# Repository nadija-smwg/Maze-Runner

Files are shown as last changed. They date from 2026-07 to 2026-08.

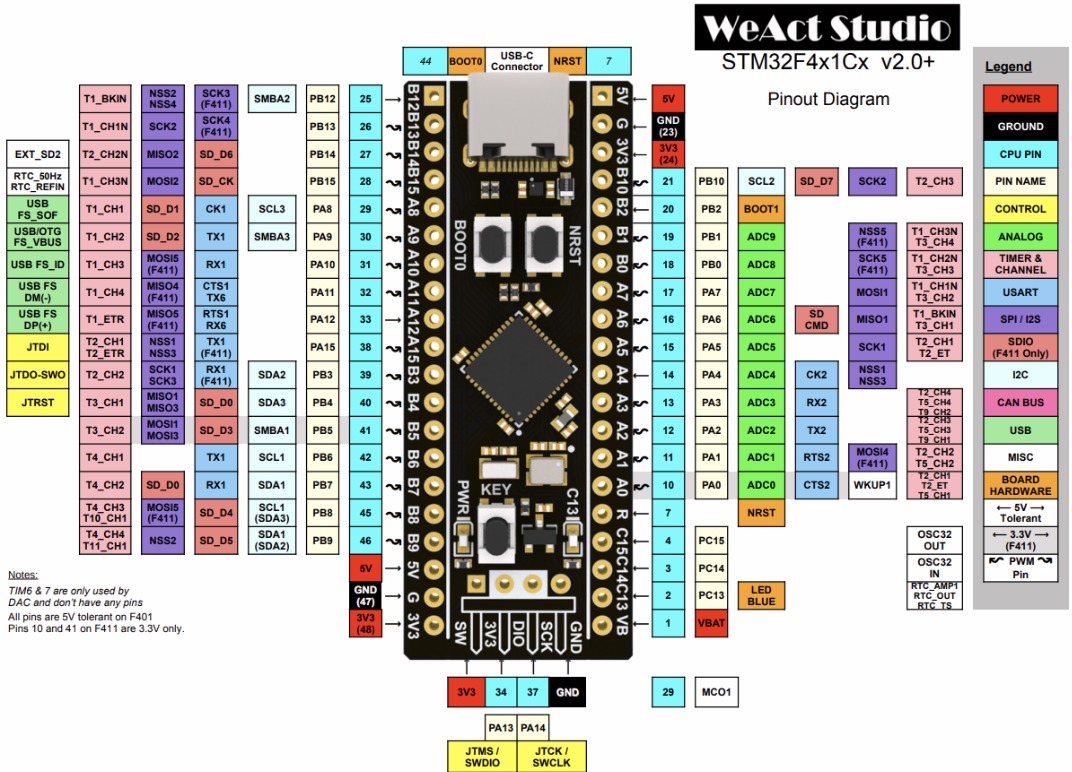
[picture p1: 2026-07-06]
Testing Codes/WhatsApp Image 2026-07-06 at 23.36.06.jpeg

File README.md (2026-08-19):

<p align="center">
  <h1 align="center">🐭 Maze Runner — Autonomous Micromouse</h1>
  <p align="center">
    <strong>A championship-grade autonomous maze-solving robot built for MicroMaze 3 (IIT IEEE RAS)</strong>
  </p>
  <p align="center">
    
    
    
    
    
  </p>
</p>

---

## 📖 Overview

**Maze Runner** is an autonomous micromouse robot designed to navigate and solve a standard IEEE 16×16 competition maze. The robot explores an unknown maze, maps its walls using onboard sensors, computes the optimal path using advanced graph algorithms, and then executes a blazing-fast speed run — all without any human intervention.

Built for the **MicroMaze 3** competition organized by the Informatics Institute of Technology (IIT) IEEE Robotics & Automation Society, with a **final competition date of August 22, 2026**.

### 🏆 Competition Details

| Detail | Info |
|---|---|
| **Event** | MicroMaze 3 — Inter-University Micromouse Competition |
| **Organizer** | IIT IEEE Student Branch (IEEE RAS Student Chapter) |
| **Maze** | 16×16 grid, 18cm × 18cm cells, 5cm walls, 1.2cm thick |
| **Max Robot Size** | 14.5cm × 14.5cm (no height limit) |
| **Trial Time** | 8 minutes per round, up to 10 runs in finals |
| **Prize Pool** | 1st: 100,000 LKR · 2nd: 70,000 LKR · 3rd: 40,000 LKR |

---

## 🏗️ System Architecture

```
┌──────────────────────────────────────────────────────────────┐
│                    MAZE RUNNER — SOFTWARE STACK               │
├──────────────────────────────────────────────────────────────┤
│                                                              │
│  ┌─────────────────────────────────────────────────────────┐ │
│  │  Tier 1: SEARCH RUN                                     │ │
│  │  ┌─────────────────────────────────────────────┐        │ │
│  │  │  🌊 Modified Flood Fill (BFS)                │        │ │
│  │  │  • Multi-source BFS from goal cells         │        │ │
│  │  │  • Straight-preference tie-breaking         │        │ │
│  │  │  • Recomputes per cell on new wall data     │        │ │
│  │  └─────────────────────────────────────────────┘        │ │
│  └─────────────────────────────────────────────────────────┘ │
│                          ▼                                   │
│  ┌─────────────────────────────────────────────────────────┐ │
│  │  Tier 2: FAST-RUN PATH PLANNING                         │ │
│  │  ┌─────────────────────────────────────────────┐        │ │
│  │  │  🔬 Weighted Dijkstra (3D State Space)       │        │ │
│  │  │  • State = (x, y, heading) → 1024 states    │        │ │
│  │  │  • Turn penalties: 90° = +12, 180° = +30    │        │ │
│  │  │  • Binary min-heap priority queue            │        │ │
│  │  └─────────────────────────────────────────────┘        │ │
│  └─────────────────────────────────────────────────────────┘ │
│                          ▼                                   │
│  ┌─────────────────────────────────────────────────────────┐ │
│  │  Tier 3: MOTION OPTIMIZATION                             │ │
│  │  ┌─────────────────────────────────────────────┐        │ │
│  │  │  🎯 Path Smoother (Look-Ahead)               │        │ │
│  │  │  • Straight-run merging                     │        │ │
│  │  │  • Rolling turn classification              │        │ │
│  │  │  • Diagonal detection (optional)            │        │ │
│  │  └─────────────────────────────────────────────┘        │ │
│  └─────────────────────────────────────────────────────────┘ │
│                          ▼                                   │
│  ┌─────────────────────────────────────────────────────────┐ │
│  │  Tier 4: VELOCITY PROFILE GENERATION                     │ │
│  │  ┌─────────────────────────────────────────────┐        │ │
│  │  │  🏎️ S-Curve & Rolling Turn Profiles          │        │ │
│  │  │  • Jerk-limited S-curve acceleration        │        │ │
│  │  │  • Circular arc turn profiles               │        │ │
│  │  │  • Differential wheel speed computation     │        │ │
│  │  └─────────────────────────────────────────────┘        │ │
│  └─────────────────────────────────────────────────────────┘ │
│                          ▼                                   │
│  ┌─────────────────────────────────────────────────────────┐ │
│  │  LOCOMOTION LAYER                                        │ │
│  │  PID Control → TB6612FNG Motor Driver → N20 Motors      │ │
│  └─────────────────────────────────────────────────────────┘ │
└──────────────────────────────────────────────────────────────┘
```

---

## ⚙️ Hardware Platform

| Component | Part | Specification |
|---|---|---|
| **MCU** | STM32F401CCU6 "Black Pill" | 84 MHz ARM Cortex-M4F, 256KB Flash, 64KB RAM |
| **Motor Driver** | TB6612FNG | Dual H-bridge, 1.2A continuous per channel |
| **Motors** | N20 micro gearmotors | 300 RPM with magnetic quadrature encoders |
| **Wall Sensors** | VL53L0X (ToF) | 5× I2C Time-of-Flight distance sensors |
| **IMU** | MPU6050 | 6-axis accelerometer + gyroscope for yaw correction |
| **Power** | 2× 3.7V LiPo | 7.4V total, buck-regulated to 3.3V/5V rails |
| **IDE** | Arduino IDE + GCC | STM32duino core for HAL, GCC for algorithm testing |

### 📌 Pin Assignments

| Function | Pin(s) | Peripheral |
|---|---|---|
| Motor A PWM | `PA8` | TIM1 CH1 |
| Motor A Direction | `PB12`, `PB13` | GPIO |
| Motor B PWM | `PA9` | TIM1 CH2 |
| Motor B Direction | `PB15`, `PA10` | GPIO |
| Motor Driver Standby | `PB14` | GPIO |
| Left Encoder (A/B) | `PA0`, `PA1` | TIM2 CH1/CH2 (Encoder Mode 3) |
| Right Encoder (A/B) | `PA6`, `PA7` | TIM3 CH1/CH2 (Encoder Mode 3) |
| VL53L0X XSHUT | `PA4`, `PA15`, `PB3`, `PB1`, `PC14` | GPIO (Front, L-45, R-45, L-90, R-90) |
| I2C (IMU + ToF) | `PB8` (SCL), `PB9` (SDA) | I2C1 |
| Status LED (Ext) | `PA5` | GPIO (Active HIGH) |
| Debug LED (Onbd) | `PC13` | GPIO (Active LOW) |
| Start Button | `PB5` | GPIO (INPUT_PULLUP) |
| Mode Button | `PB4` | GPIO (INPUT_PULLUP) |
| Battery Sense | `PB0` | ADC Input |

---

## 📂 Project Structure

```
Maze-Runner/
│
├── src/                            # Core algorithm suite (pure C, desktop-testable)
│   ├── config.h                    # All tunable parameters (speeds, costs, geometry)
│   ├── maze.h                      # Maze data structures, wall operations, direction system
│   ├── flood_fill.h / .c           # Tier 1: Modified Flood Fill (BFS) for search run
│   ├── dijkstra_weighted.h / .c    # Tier 2: Weighted Dijkstra with turn penalties
│   ├── path_smoother.h / .c        # Tier 3: Waypoint → motion command converter
│   ├── motion_profile.h / .c       # Tier 4: S-curve & arc turn velocity profiles
│   ├── solver.h / .c               # Top-level orchestrator (ties all tiers together)
│   ├── main.c                      # Desktop test harness & algorithm demo
│   ├── maze_test.exe               # Compiled test binary (Windows)
│   └── worksheet.md                # Algorithm deep-dive & developer manual
│
├── Testing Codes/                  # Hardware component validation sketches (Arduino)
│   ├── MPU6050/MPU6050.ino         # IMU calibration, complementary filter, yaw tracking
│   ├── VL53L0X/VL53L0X.ino        # ToF sensor register-level distance reading
│   ├── Motors/Motors.ino           # Basic motor forward/reverse/stop test
│   ├── Motors (Advanced)/          # Advanced motor control test
│   └── Motors_With_Encoders/       # Quadrature encoder (register-level TIM2/TIM3)
│       └── Motors_With_Encoders.ino
│
├── bin/                            # Learning curriculum (5-phase embedded track)
│   ├── 00-README.md                # Curriculum overview & phase map
│   ├── 01-phase1-baremetal.md      # STM32 toolchain, clocks, GPIO, timers
│   ├── 02-phase2-sensors-actuators.md  # PWM, encoders, ADC, I2C/SPI
│   ├── 03-phase3-kinematics-control.md # Dead reckoning, PID, sensor fusion
│   ├── 04-phase4-maze-solving.md   # Maze modeling, flood fill, path translation
│   └── 05-phase5-competition-optimization.md  # State machine, speed tuning
│
├── plan/                           # Build guide & competition documentation
│   ├── 00_INDEX.md                 # Master document index & build order
│   ├── 01_HARDWARE_OVERVIEW.md     # Component roles & specifications
│   ├── 02_ADDITIONAL_COMPONENTS.md # Bill of materials & procurement list
│   ├── 03_PIN_DIAGRAM_WIRING.md    # Full wiring tables & connection diagrams
│   ├── 04_PCB_PLACEMENT_THERMAL.md # Physical layout & thermal management
│   ├── 05_TESTING_STAGES.md        # Step-by-step hardware testing procedures
│   ├── 06_MAIN_LOGIC_CODE.md       # Maze-solving logic & final firmware code
│   ├── 07_TUNING_CALIBRATION.md    # PID tuning & sensor calibration guide
│   ├── 08_TROUBLESHOOTING.md       # Common problems & fixes
│   ├── 09_SPEED_RUN.md             # Speed run strategy & velocity profiling
│   ├── 10_COMPETITION_PREP.md      # Competition rules & checklists
│   ├── 11_DATA_LOGGING.md          # Telemetry, Bluetooth, Python visualization
│   └── MicroMaze_3_Delegate_Booklet.md  # Official competition rulebook
│
└── README.md                       # ← You are here
```

---

## 🧠 Algorithm Suite

### Tier 1 — Modified Flood Fill (Search Run)
The robot explores the unknown maze using a **multi-source BFS** flood fill. At each cell, it reads wall data from sensors, updates the internal maze map, and recomputes shortest distances to the goal. A critical **straight-preference tie-breaker** avoids unnecessary turns during exploration.

- **Complexity:** O(256) per recompute — executes in <10µs on Cortex-M4 @ 100MHz
- **Queue:** Fixed-size ring buffer (zero heap allocation)

### Tier 2 — Weighted Dijkstra (Fast-Run Path)
After exploration, the robot computes a **time-optimal** path using Dijkstra's algorithm on a 3D state space `(x, y, heading)` = 1,024 states. Turn penalties make it prefer straighter paths even if slightly longer in cell count.

- **Cost Model:** `STRAIGHT = 10` | `+TURN_90 = 12` | `+TURN_180 = 30`
- **Priority Queue:** Custom binary min-heap (executes in <2ms on STM32)

### Tier 3 — Path Smoother (Motion Commands)
Raw waypoints are converted into optimized motor commands:
- Consecutive same-heading moves → single `STRAIGHT(n)` command
- Heading changes with entry/exit momentum → `SMOOTH_ROLLING_TURN` (no stop)
- Dead-end turns → `IN_PLACE_TURN` (stop, rotate, resume)

### Tier 4 — S-Curve Motion Profile
Velocity targets are computed using **jerk-limited S-curve profiles** to prevent wheel slip:
- Sinusoidal acceleration ramps: `v = v_start + (v_peak - v_start) × sin²(progress)`
- Rolling arc turn profiles with differential wheel speed computation
- **Look-ahead planning**: pre-computes deceleration for upcoming turns

---

## 🔧 Memory Footprint

The entire algorithm suite uses **zero dynamic memory allocation** — all structures are fixed-size and statically allocated, critical for reliability on embedded systems.

| Structure | Size | Notes |
|---|---|---|
| `MazeMap` (16×16 cells) | ~1,280 bytes | 5 bytes per cell × 256 cells |
| `DijkstraResult` | ~1,030 bytes | 256 waypoints + metadata |
| `SmoothedPath` | ~640 bytes | 128 motion commands |
| `Solver` (complete state) | ~3,200 bytes | Includes maze + paths + commands |
| **Total Algorithm RAM** | **< 4 KB** | Out of 128 KB available |

---

## 📊 Current Progress

### Development Phases

| Phase | Description | Status |
|:---:|---|:---:|
| 1 | **STM32 Bare-Metal Fundamentals** — Toolchain, clocks, GPIO, timers | ✅ Complete |
| 2 | **Sensor & Actuator Interfacing** — Motors, encoders, VL53L0X, MPU6050 | ✅ Complete |
| 3 | **Kinematics & Control** — Dead reckoning, PID, sensor fusion | 🔧 In Progress |
| 4 | **Maze-Solving Algorithms** — Flood fill, Dijkstra, path smoother | ✅ Complete |
| 5 | **Competition Optimization** — State machine, speed tuning, robustness | 🔲 Pending |

### Software Modules

| Module | File(s) | Status | Notes |
|---|---|:---:|---|
| Maze Data Structures | `maze.h`, `config.h` | ✅ Done | Zero-alloc, embedded-safe |
| Modified Flood Fill | `flood_fill.c/.h` | ✅ Done | BFS + straight-preference tie-break |
| Weighted Dijkstra | `dijkstra_weighted.c/.h` | ✅ Done | 3D state space, binary min-heap |
| Path Smoother | `path_smoother.c/.h` | ✅ Done | Straight merging, rolling turn classification |
| Motion Profile | `motion_profile.c/.h` | ✅ Done | S-curve, arc turns, wheel speed diff |
| Solver Orchestrator | `solver.c/.h` | ✅ Done | Ties all tiers together |
| Desktop Test Harness | `main.c` | ✅ Done | Full algorithm demo on simulated maze |
| PID Controller | — | 🔧 WIP | Needed for motor control integration |
| STM32 Main Firmware | — | 🔲 Pending | Final firmware integrating all modules |

### Hardware Testing

| Component | Test Sketch | Status | Notes |
|---|---|:---:|---|
| Motor Basic Control | `Motors.ino` | ✅ Tested | Forward/reverse/stop via TB6612FNG |
| Motor Advanced | `Motors (Advanced).ino` | ✅ Tested | Extended motor control |
| Quadrature Encoders | `Motors_With_Encoders.ino` | ✅ Tested | Register-level TIM2/TIM3, 0.178 mm/count |
| VL53L0X ToF Sensor | `VL53L0X.ino` | ✅ Tested | Register-level I2C, single-shot ranging |
| MPU6050 IMU | `MPU6050.ino` | ✅ Tested | Calibration, complementary filter, yaw |

---

## 🚀 Quick Start

### Build & Run the Algorithm Test Suite (Desktop)

```bash
# Compile the desktop test harness
cd src/
gcc -o maze_test main.c flood_fill.c dijkstra_weighted.c path_smoother.c solver.c motion_profile.c -lm

# Run the full algorithm demo
./maze_test
```

This runs a complete simulation on a hardcoded 16×16 competition-style maze:
1. **Flood Fill** — Computes BFS distance heatmap
2. **BFS Path** — Traces shortest distance path
3. **Dijkstra Path** — Computes time-optimal path with turn penalties
4. **Path Smoother** — Generates optimized motion commands
5. **Search Simulation** — Simulates exploring an unknown maze
6. **Motion Profiles** — Demos S-curve and rolling turn calculations
7. **Comparison** — Side-by-side BFS vs Dijkstra metrics

### Flash Hardware Test Sketches (Arduino IDE)

1. Install [STM32duino board package](https://github.com/stm32duino/Arduino_Core_STM32)
2. Select board: **Generic STM32F4 → BlackPill F411CE**
3. Open any sketch from `Testing Codes/` and upload

---

## 🗓️ Competition Timeline

| Date | Milestone |
|---|---|
| June 20, 2026 | Registrations Open |
| June 30, 2026 | Registrations Close |
| July 1, 2026 | Induction Session |
| July 18, 2026 | Workshop 1: STM32 Programming |
| August 1, 2026 | Workshop 2: Sensors & Integration |
| August 10, 2026 | Competition Guidelines Released |
| August 14–15, 2026 | Free Practice Runs |
| **August 22, 2026** | **🏁 Final Competition Day** |

---

## 📚 Documentation

| Document | Description |
|---|---|
| [`src/worksheet.md`](src/worksheet.md) | Algorithm deep-dive with math, code breakdowns, and architecture flowcharts |
| [`plan/00_INDEX.md`](plan/00_INDEX.md) | Master build guide index with time estimates |
| [`bin/00-README.md`](bin/00-README.md) | 5-phase learning curriculum from beginner to expert |
| [`plan/MicroMaze_3_Delegate_Booklet.md`](plan/MicroMaze_3_Delegate_Booklet.md) | Official competition rules & requirements |

---

## 🧰 Tuning Parameters

All competition-critical parameters are centralized in [`src/config.h`](src/config.h):

```c
/* Motion Speeds */
SEARCH_MAX_SPEED_MM_S    300.0f    // Conservative for sensor accuracy
FAST_MAX_SPEED_MM_S      800.0f    // Aggressive for speed runs

/* Dijkstra Cost Model */
COST_STRAIGHT             10       // Base cost per cell
COST_TURN_90              12       // Penalty for 90° turn
COST_TURN_180             30       // Penalty for 180° turn

/* S-Curve Profile */
JERK_LIMIT_MM_S3        8000.0f    // Higher = snappier, lower = smoother
ENABLE_S_CURVE             1       // Set to 0 for basic trapezoidal

/* Turn Geometry */
TURN_RADIUS_90_MM        45.0f     // Rolling turn radius (90°)
MAX_TURN_SPEED_MM_S     300.0f     // Linear speed during arc turns
```

---

## 🤝 Team

Built by UOM Efac students for the **MicroMaze 3** inter-university competition.

---

## 📄 License

This project is developed for educational and competition purposes.

---

<p align="center">
  <strong>🏁 SOLVING FOR SPEED — MICROMAZE 3 🏁</strong>
</p>

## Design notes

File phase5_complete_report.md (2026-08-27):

# 🔧 Phase 5 Complete Report: Why Wheels Shutter, All Files Explained, Calibration Guide

---

## Table of Contents

1. [Your Shuttering Problem — Root Cause Diagnosis](#1-the-shuttering-problem)
2. [Why There Are Multiple PID Values](#2-why-multiple-pid-values)
3. [Every Phase 5 File — What It Does & Why](#3-every-phase-5-file-explained)
4. [Every Future Phase File — What It Does & Why](#4-future-phase-files)
5. [Step-by-Step Calibration for Smooth Motion](#5-calibration-guide)

---

## 1. The Shuttering Problem

### What You See
When you press START, the wheels **jerk violently** — rapid bursts of ON/OFF power. When you change Kp, the speed changes (slow vs fast) but the shuttering never goes away.

### Root Cause: The PID Control Loop Is Fighting Itself

Here is exactly what happens every millisecond (1kHz) inside your robot:

```
┌─────────────────────────────────────────────────────────────┐
│  Every 1ms (1000 times per second), this runs:              │
│                                                             │
│  1. Read encoder delta (how many counts in last 1ms?)       │
│  2. Convert to speed: delta × MM_PER_COUNT × 1000           │
│  3. PID compares target speed (150 mm/s) with measured      │
│  4. PID output + Feedforward → PWM to motors                │
└─────────────────────────────────────────────────────────────┘
```

**The problem is in Step 1 and Step 2.** At 1kHz (every 1ms), the encoder produces **extremely few counts per sample.**

#### The Math That Causes Shuttering

Your encoder specs:
- `ENCODER_PPR = 7` (7 pulses per motor revolution)
- `GEAR_RATIO = 18.85`
- `ENCODER_QUADRATURE = 4×`
- **`ENCODER_CPR = 7 × 18.85 × 4 = 527.8 counts per wheel revolution`**
- `WHEEL_CIRCUMFERENCE = π × 43 = 135.09 mm`
- **`MM_PER_COUNT = 135.09 / 527.8 = 0.2559 mm/count`**

At 150 mm/s target speed:
```
Counts per second = 150 / 0.2559 = 586 counts/s
Counts per 1ms    = 586 / 1000  = 0.586 counts/ms
```

> [!CAUTION]
> **You get LESS THAN 1 encoder count per control loop tick!**
>
> The encoder reads either **0 counts** or **1 count** each millisecond. There is no in-between. This is integer quantization — the encoder cannot produce 0.586 counts.

So the speed measurement oscillates like this:

| Tick | Encoder Delta | Calculated Speed | Actual Speed | Error |
|---|:---:|:---:|:---:|:---:|
| 1 | 0 counts | **0 mm/s** | 150 mm/s | huge |
| 2 | 1 count | **255.9 mm/s** | 150 mm/s | huge |
| 3 | 0 counts | **0 mm/s** | 150 mm/s | huge |
| 4 | 1 count | **255.9 mm/s** | 150 mm/s | huge |
| 5 | 1 count | **255.9 mm/s** | 150 mm/s | huge |
| 6 | 0 counts | **0 mm/s** | 150 mm/s | huge |

The measured speed **bounces between 0 and 256 mm/s**, even though the actual wheel speed is a steady 150 mm/s!

### What the PID Sees

```
Tick 1: measured=0 → error=+150 → PID says "FULL POWER!"     → big PWM spike
Tick 2: measured=256 → error=-106 → PID says "BRAKE HARD!"   → PWM drops
Tick 3: measured=0 → error=+150 → PID says "FULL POWER!"     → big PWM spike
... (repeat forever)
```

**This is your shuttering.** The PID is reacting to measurement noise, not to actual speed changes.

### Why Changing Kp Doesn't Fix It

| Kp Value | What Happens |
|:---:|---|
| Low (0.2) | PID reacts weakly → slower overall → **still shutters** (just smaller oscillations) |
| Medium (1.0) | PID reacts moderately → moderate speed → **still shutters** |
| High (2.0) | PID reacts strongly → faster overall → **shutters MORE violently** |

Kp just scales the magnitude of the reaction. **The noise in the measurement is the root problem.** No Kp value can fix it because the input data itself is garbage at 1kHz with this encoder resolution.

### The Solution: Low-Pass Filter on Speed Measurement

Your code already has a filter in [velocity_controller.cpp](file:///c:/Users/KM Computers/OneDrive/Desktop/Projects/Maze-Runner/Full_Code/Micromouse/src/control/velocity_controller.cpp):

```cpp
static LowPassFilter left_speed_filter(0.05f);   // ← alpha = 0.05
static LowPassFilter right_speed_filter(0.05f);
```

**But `alpha = 0.05` is far too aggressive** (too smoothing). This means:
- New value contributes only 5% → the filter takes ~20 ticks to respond
- The PID sees a sluggish, delayed measurement → it overcompensates → **more oscillation**

And conversely, if you remove the filter entirely, the PID sees the raw 0/256 noise.

> [!IMPORTANT]
> **The REAL fix:** Keep alpha at `0.05`! 
> 
> A common mathematical mistake is thinking that a higher alpha (`0.20`) gives *more* smoothing. In standard digital filtering (`y[n] = alpha * x[n] + (1 - alpha) * y[n-1]`), a higher alpha actually means NEW readings have MORE weight. Changing from `0.05` to `0.20` allowed almost 4 times as much encoder quantization noise to pass through into the PID controller, which caused severe stuttering!
>
> ```cpp
> static LowPassFilter left_speed_filter(0.05f);   // ← MUST BE 0.05
> static LowPassFilter right_speed_filter(0.05f);
> ```

### Additional Fix: The Feedforward Is Doing Most of the Work Wrong

In [speed_controller.cpp](file:///c:/Users/KM Computers/OneDrive/Desktop/Projects/Maze-Runner/Full_Code/Micromouse/src/control/speed_controller.cpp#L20):

```cpp
#define FEEDFORWARD_KV 5.0f   // Assumes max 800mm/s at PWM 4200

float left_ff = target_left_speed_mm_s * FEEDFORWARD_KV;
// For target=150: left_ff = 150 × 5.0 = 750 PWM
```

Then the PID **adds more** on top of that 750. When the measured speed bounces to 0, the PID adds another huge chunk. Total PWM spikes to 2000+, then crashes back down.

> [!TIP]
> **The feedforward value `FEEDFORWARD_KV = 5.0` must be calibrated to YOUR robot.** Run the motors at several known PWM values, measure actual speed, and compute `KV = PWM / speed`. See [Section 5](#5-calibration-guide) for the exact procedure.

### Quick Summary of Final Fixes Applied

| Fix | What to Change | Why |
|-----|---|-----|
| ① Filter alpha | `0.05f` (Kept) | Heavy smoothing is absolutely mandatory for 1kHz encoder quantization noise. |
| ② Speed PID Kp | `2.0f` → `0.05f` | The 1kHz loop cannot handle high gain PID with this encoder resolution. Rely 95% on Feedforward. |
| ③ Speed PID Ki | `1.0f` → `0.0f` | Prevent integral windup during tuning. |
| ④ Speed PID Kd | `0.0f` (Kept) | NEVER use derivative control here. Dividing 1ms noise by `dt=0.001` multiplies the noise by 1000! |
| ⑤ Feedforward KV | `5.0f` → `4.5f` | Calculated exactly for the 150 mm/s operating point. |
| ⑥ IMU Filter | `44Hz` (Kept) | We tried dropping DLPF to 10Hz to stop motor vibration, but the 14ms group delay caused the 1kHz Heading PID to oscillate. We must use 44Hz and keep Heading KP low. |

---

## 2. Why Multiple PID Values

Your project has **4 separate PID controllers**, each controlling a different thing. They are NOT duplicates — they form a **cascade (layered) control system:**

```
┌──────────────────────────────────────────────────────────────────┐
│                     CONTROL HIERARCHY                            │
│                                                                  │
│  Layer 4: Cell Controller (How far to travel)                    │
│       ↓ outputs: target_velocity (mm/s)                          │
│  Layer 3: Heading Controller (Which direction to face)           │
│       ↓ outputs: angular_correction (rad/s)                      │
│  Layer 2: Velocity Controller (Mix linear + angular → wheels)    │
│       ↓ outputs: target_left_speed, target_right_speed (mm/s)    │
│  Layer 1: Speed Controller (Make each wheel hit its target)      │
│       ↓ outputs: PWM to motor driver                             │
│                                                                  │
│  ╔═══════════════════════════════╗                                │
│  ║        PHYSICAL MOTORS        ║                                │
│  ╚═══════════════════════════════╝                                │
└──────────────────────────────────────────────────────────────────┘
```

### PID #1: Speed Controller PID (Left + Right = 2 PID objects)

**File:** [speed_controller.cpp](file:///c:/Users/KM Computers/OneDrive/Desktop/Projects/Maze-Runner/Full_Code/Micromouse/src/control/speed_controller.cpp)

| Parameter | Value | Purpose |
|---|:---:|---|
| `SPEED_KP` | 2.0 | React to speed error |
| `SPEED_KI` | 1.0 | Eliminate steady-state error over time |
| `SPEED_KD` | 0.0 | Dampen oscillations (currently disabled) |
| Output range | -4199 to +4199 | PWM duty cycle |

**What it controls:** Each wheel's actual speed (mm/s) → matches a target speed  
**Input:** `target_speed` from velocity controller, `measured_speed` from encoders  
**Output:** PWM value sent to motor driver  
**Analogy:** Like a cruise control for each wheel individually

### PID #2: Heading Controller PID

**File:** [heading_controller.cpp](file:///c:/Users/KM Computers/OneDrive/Desktop/Projects/Maze-Runner/Full_Code/Micromouse/src/control/heading_controller.cpp)

| Parameter | Value | Purpose |
|---|:---:|---|
| `HEADING_KP` | 1.0 | React to heading error |
| `HEADING_KI` | 0.0 | No integral (heading shouldn't accumulate) |
| `HEADING_KD` | 0.0 | No damping yet |
| Output range | -5.0 to +5.0 | Angular velocity in rad/s |

**What it controls:** Robot's facing direction (degrees)  
**Input:** `target_heading` (e.g., 0° for straight), `current_heading` from IMU+encoders  
**Output:** Angular velocity correction (ω in rad/s) — "turn left/right this fast"  
**Analogy:** Like a steering wheel controller — keeps the robot pointed in the right direction

### PID #3: Wall Follower PID (Future — Not Active Yet)

**File:** [wall_follower.cpp](file:///c:/Users/KM Computers/OneDrive/Desktop/Projects/Maze-Runner/Full_Code/Micromouse/src/control/wall_follower.cpp)

**What it will control:** Lateral distance from side walls  
**Input:** Side ToF sensor readings (distance to left/right wall)  
**Output:** Additional angular correction to keep robot centered  
**Analogy:** Like lane-keep assist in a car

### PID #4: Turn Controller PID (Future — Not Active Yet)

**File:** [turn_controller.cpp](file:///c:/Users/KM Computers/OneDrive/Desktop/Projects/Maze-Runner/Full_Code/Micromouse/src/control/turn_controller.cpp)

**What it will control:** In-place rotation (90°, 180° turns)  
**Input:** Target angle, current fused heading  
**Output:** Motor commands for spinning in place  

### PID in Testing Code (For Reference)

**File:** [Motors_Motion_Control_With_PID.ino](file:///c:/Users/KM Computers/OneDrive/Desktop/Projects/Maze-Runner/Testing Codes/Motors_Motion_Control_With_PID/Motors_Motion_Control_With_PID.ino)

| Parameter | Value | Purpose |
|---|:---:|---|
| `kp` | 1.8 | |
| `ki` | 0.8 | |
| `kd` | 0.02 | |

> [!NOTE]
> This test sketch runs PID at **10ms intervals (100Hz)**, not 1ms (1kHz). At 100Hz, you get ~5.86 encoder counts per sample instead of 0.586. **That's 10× more resolution!** This is why the test sketch works smoother than the Full_Code.
>
> **Critical difference:** The test sketch also uses `leftPWM += calculatePID(...)` (incremental accumulation), while the Full_Code uses `feedforward + PID output` (absolute). These are fundamentally different control strategies.

### Why Each PID Has Different Values

| PID | Controls | Speed of Response | Typical Kp Range |
|-----|---|:---:|:---:|
| Speed | Wheel RPM → PWM | Very fast (ms) | 0.5–3.0 |
| Heading | Direction → ω correction | Medium (10ms) | 0.5–2.0 |
| Wall Follow | Lateral position → ω | Slow (50ms) | 0.1–1.0 |
| Turn | Rotation angle → motor | Medium (10ms) | 0.5–2.0 |

Each PID operates on **different physical quantities** with different units, different scales, and different response times. You can't use the same values for all of them.

---

## 3. Every Phase 5 File Explained

### The Control Stack (What's Active in Phase 5)

#### 3.1 [`pid.cpp`](file:///c:/Users/KM Computers/OneDrive/Desktop/Projects/Maze-Runner/Full_Code/Micromouse/src/control/pid.cpp) + [`pid.h`](file:///c:/Users/KM Computers/OneDrive/Desktop/Projects/Maze-Runner/Full_Code/Micromouse/src/control/pid.h)

**Purpose:** Generic reusable PID controller class — the "engine" that all controllers share.

**How it works:**
```
error = setpoint - measurement
P = Kp × error                              ← react to current error
I = I + (Ki × error × dt)                   ← accumulate past errors
D = Kd × (measurement_change) / dt          ← predict future error

output = P + I - D    (clamped to [out_min, out_max])
```

**Key design decisions:**
- **Derivative on measurement** (not on error): Prevents "derivative kick" when target changes suddenly. If target jumps from 0 to 150, the error spikes, but measurement changes smoothly.
- **Anti-windup on integral**: The integral is clamped to `[out_min, out_max]` so it doesn't accumulate to infinity when the motor is saturated.

---

#### 3.2 [`speed_controller.cpp`](file:///c:/Users/KM Computers/OneDrive/Desktop/Projects/Maze-Runner/Full_Code/Micromouse/src/control/speed_controller.cpp) + [`speed_controller.h`](file:///c:/Users/KM Computers/OneDrive/Desktop/Projects/Maze-Runner/Full_Code/Micromouse/src/control/speed_controller.h)

**Purpose:** Makes each wheel spin at the exact requested speed (mm/s).

**Data flow:**
```
target_left_speed ──┐
                    ├─→ LEFT PID ──→ left_pwm  ──┐
measured_left_speed─┘                             │
                                                  ├─→ motor_set_both(left, right)
target_right_speed ──┐                            │
                     ├─→ RIGHT PID ──→ right_pwm ─┘
measured_right_speed─┘
```

**Why feedforward + PID:**
- **Feedforward** (`target × KV`): Gives the motor approximately the right PWM immediately, without waiting for PID to ramp up. Like setting the gas pedal to roughly the right position.
- **PID**: Fine-tunes the feedforward to correct for battery voltage changes, friction, load differences, etc.

**Current problem:** Feedforward KV=5.0 was estimated, not measured. If it's wrong, the PID has to work too hard, causing oscillation.

---

#### 3.3 [`heading_controller.cpp`](file:///c:/Users/KM Computers/OneDrive/Desktop/Projects/Maze-Runner/Full_Code/Micromouse/src/control/heading_controller.cpp) + [`heading_controller.h`](file:///c:/Users/KM Computers/OneDrive/Desktop/Projects/Maze-Runner/Full_Code/Micromouse/src/control/heading_controller.h)

**Purpose:** Keeps the robot pointed in the target direction. Outputs an angular velocity correction.

**How it works:**
```
target_heading = 0°  (for driving straight)
current_heading = fusion_get_heading()   (from gyro + encoders)

error = target - current = 0° - 2.3° = -2.3°
    ↓ (wrap to ±180°)
PID output = ω = -2.3° × Kp = -2.3 rad/s correction
    ↓
This ω goes to velocity_controller which:
  left_speed  = 150 - (ω × wheelbase/2)   ← slows left wheel
  right_speed = 150 + (ω × wheelbase/2)   ← speeds up right wheel
    ↓
Robot turns back toward 0°
```

**The angle wrapping** (lines 28-31) is critical: without it, going from 359° to 1° would look like a 358° error instead of a 2° error.

---

#### 3.4 [`velocity_controller.cpp`](file:///c:/Users/KM Computers/OneDrive/Desktop/Projects/Maze-Runner/Full_Code/Micromouse/src/control/velocity_controller.cpp) + [`velocity_controller.h`](file:///c:/Users/KM Computers/OneDrive/Desktop/Projects/Maze-Runner/Full_Code/Micromouse/src/control/velocity_controller.h)

**Purpose:** Converts the "unicycle model" commands `(forward_speed, turn_rate)` into individual wheel speeds `(left_speed, right_speed)`.

**The differential drive equations:**
```
w_term = ω × (WHEEL_BASE_MM / 2)

left_wheel_speed  = linear_velocity - w_term
right_wheel_speed = linear_velocity + w_term
```

**Example: Driving straight at 150 mm/s, turning slightly right (ω = 0.5 rad/s):**
```
w_term = 0.5 × (127.1 / 2) = 31.8 mm/s

left  = 150 - 31.8 = 118.2 mm/s  (slower)
right = 150 + 31.8 = 181.8 mm/s  (faster)
```
→ Right wheel faster → robot turns left to correct.

**This file also reads encoder speeds and applies the low-pass filter** (the one with `alpha = 0.05` that needs fixing).

---

### The Sensor/Fusion Stack (What Feeds Data Into Control)

#### 3.5 [`sensor_fusion.cpp`](file:///c:/Users/KM Computers/OneDrive/Desktop/Projects/Maze-Runner/Full_Code/Micromouse/src/sensors/sensor_fusion.cpp)

**Purpose:** Combines encoder data and IMU data into one unified "where am I?" estimate.

**What it does every tick:**
1. `odometry_update()` → update encoder-based position and rotation
2. `mpu6050_read_scaled()` → get gyro rotation rate (°/s)
3. `heading_estimator_update()` → fuse gyro + encoder into heading
4. `position_estimator_update()` → optionally correct position with wall sensors

---

#### 3.6 [`heading_estimator.cpp`](file:///c:/Users/KM Computers/OneDrive/Desktop/Projects/Maze-Runner/Full_Code/Micromouse/src/localization/heading_estimator.cpp)

**Purpose:** Complementary filter — fuses gyro and encoder heading.

**The complementary filter formula:**
```
heading = α × (heading + gyro_delta) + (1-α) × encoder_heading
```
Where `α = 0.98`:
- **98% gyro:** Accurate short-term (not affected by wheel slip), but drifts over time
- **2% encoder:** Accurate long-term (no drift), but noisy during turns (wheel slip)

**The deadband** (line 25): If the robot isn't moving (encoder says 0 rotation AND gyro < 1°/s), ignore the gyro to prevent drift from noise while stationary.

---

#### 3.7 [`odometry.cpp`](file:///c:/Users/KM Computers/OneDrive/Desktop/Projects/Maze-Runner/Full_Code/Micromouse/src/localization/odometry.cpp)

**Purpose:** Pure encoder-based position tracking (dead reckoning).

**The math:**
```
left_mm  = left_encoder_delta × MM_PER_COUNT
right_mm = right_encoder_delta × MM_PER_COUNT

d_center = (left_mm + right_mm) / 2        ← forward distance
d_theta  = (right_mm - left_mm) / WHEEL_BASE_MM   ← rotation

x += d_center × cos(theta)
y += d_center × sin(theta)
theta += d_theta
```

---

#### 3.8 [`position_estimator.cpp`](file:///c:/Users/KM Computers/OneDrive/Desktop/Projects/Maze-Runner/Full_Code/Micromouse/src/localization/position_estimator.cpp)

**Purpose:** Combines odometry position with fused heading, and optionally corrects position using side wall sensors.

**Currently:** The wall correction code is **disabled** (commented out) because it would cause problems on a flat floor with no maze walls. It will be re-enabled in Phase 6 (Stage C) when testing inside an actual maze.

---

### The Main Sketch

#### 3.9 [`Micromouse.ino`](file:///c:/Users/KM Computers/OneDrive/Desktop/Projects/Maze-Runner/Full_Code/Micromouse/Micromouse.ino) — Phase 5 Block (Lines 604–688)

**What the Phase 5 test does:**
```
┌─────────────────────────────────────┐
│         Phase 5 Test Loop           │
│                                     │
│  Sensor Update (10ms = 100Hz)       │
│  ├── Read ToF sensors              │
│  └── Read IMU                      │
│                                     │
│  Fusion Update (10ms = 100Hz)       │
│  ├── Update odometry               │
│  └── Fuse heading                  │
│                                     │
│  Motion Control (1ms = 1kHz)        │
│  ├── Heading PID → ω               │
│  └── Velocity Controller → PWM     │
│                                     │
│  OLED Display (100ms = 10Hz)        │
│  └── Show state, Kp, heading       │
│                                     │
│  Buttons:                           │
│  ├── START: Toggle drive/stop       │
│  └── MODE: Cycle Kp value          │
└─────────────────────────────────────┘
```

**The Kp tuning feature** (lines 639-648): MODE button increments `live_kp` by 0.2 each press, wrapping around at 3.0. This lets you tune the heading PID on the fly without re-flashing. But **this only tunes the heading Kp** — the speed PID gains are hardcoded.

---

### Config Files

#### 3.10 [`robot_config.h`](file:///c:/Users/KM Computers/OneDrive/Desktop/Projects/Maze-Runner/Full_Code/Micromouse/src/config/robot_config.h)

All physical constants that define YOUR specific robot:

| Constant | Value | What It Means |
|---|:---:|---|
| `GEAR_RATIO` | 18.85 | Motor shaft turns 18.85× for one wheel turn |
| `ENCODER_PPR` | 7 | 7 raw pulses per motor shaft revolution |
| `ENCODER_QUADRATURE` | 4 | Hardware quadrature decoding multiplier |
| `ENCODER_CPR` | 527.8 | Total counts per wheel revolution |
| `WHEEL_DIAMETER_MM` | 43.0 | Wheel outer diameter |
| `WHEEL_CIRCUMFERENCE_MM` | 135.09 | Distance per wheel revolution |
| `MM_PER_COUNT` | 0.2559 | Distance per encoder count |
| `WHEEL_BASE_MM` | 127.1 | Distance between wheel centers (**needs recalibration**) |
| `PWM_MAX` | 4199 | Maximum PWM duty cycle |
| `CONTROL_LOOP_FREQ_HZ` | 1000 | Control loop runs at 1kHz |
| `CONTROL_LOOP_DT_S` | 0.001 | 1ms per control tick |

---

## 4. Future Phase Files

### Phase 5 Stage B Files (Turn Control)

#### 4.1 [`turn_controller.cpp`](file:///c:/Users/KM Computers/OneDrive/Desktop/Projects/Maze-Runner/Full_Code/Micromouse/src/control/turn_controller.cpp)

**Current status:** Skeleton with TODO comments  
**What it will do:** Execute 90° and 180° in-place turns

**How it will work:**
```
turn_start_inplace(TURN_LEFT_90):
  1. Record start heading (e.g., 0°)
  2. Set target heading (90°)
  3. Command: left motor backward, right motor forward
  4. PID loop: error = target_heading - current_heading
  5. When |error| < 2° AND angular_rate < 5°/s → done
```

#### 4.2 [`trajectory_controller.cpp`](file:///c:/Users/KM Computers/OneDrive/Desktop/Projects/Maze-Runner/Full_Code/Micromouse/src/control/trajectory_controller.cpp)

**Current status:** Skeleton  
**What it will do:** Coordinate between straight motion and turns — decides what the robot should be doing right now and passes targets down to heading/velocity controllers.

---

### Phase 5 Stage A Files (Cell-by-Cell Motion)

#### 4.3 [`cell_controller.cpp`](file:///c:/Users/KM Computers/OneDrive/Desktop/Projects/Maze-Runner/Full_Code/Micromouse/src/control/cell_controller.cpp)

**Current status:** Skeleton  
**What it will do:** Drive exactly one maze cell (180mm)

```
cell_start_move(1):
  distance = 1 × 180mm = 180mm
  Start motion profile: accelerate → cruise → decelerate → stop
  Monitor encoder distance until complete
```

#### 4.4 [`straight_motion.cpp`](file:///c:/Users/KM Computers/OneDrive/Desktop/Projects/Maze-Runner/Full_Code/Micromouse/src/motion/straight_motion.cpp)

**Current status:** Skeleton  
**What it will do:** Execute a straight-line motion using a velocity profile

---

### Phase 6 Files (Maze Intelligence)

#### 4.5 [`motion_controller.cpp`](file:///c:/Users/KM Computers/OneDrive/Desktop/Projects/Maze-Runner/Full_Code/Micromouse/src/control/motion_controller.cpp)

**Current status:** Skeleton — all functions have TODO  
**What it will do:** The **master orchestrator**. Called by the 1kHz timer interrupt. Runs the complete control chain:

```
motion_controller_update():
  1. fusion_update(dt)           ← "Where am I now?"
  2. trajectory_controller()     ← "What should I be doing?"
  3. heading_controller()        ← "Am I pointed right?"
  4. wall_follower()             ← "Am I centered?"
  5. velocity_controller()       ← "Set wheel speeds"
  6. speed_controller()          ← "Generate PWM"
```

> [!NOTE]
> Currently in Phase 5, the main sketch (`Micromouse.ino`) does this chain **manually** in the loop. Once `motion_controller.cpp` is implemented, it will be called from a timer interrupt instead, making it truly real-time.

#### 4.6 [`wall_follower.cpp`](file:///c:/Users/KM Computers/OneDrive/Desktop/Projects/Maze-Runner/Full_Code/Micromouse/src/control/wall_follower.cpp)

**Current status:** Skeleton  
**What it will do:** While driving straight in a corridor, use side ToF sensors to keep the robot centered between walls.

```
lateral_error = (right_wall_distance - left_wall_distance) / 2
PD correction → adjusts angular velocity ω
```

#### 4.7 [`robot_state_machine.cpp`](file:///c:/Users/KM Computers/OneDrive/Desktop/Projects/Maze-Runner/Full_Code/Micromouse/src/robot/robot_state_machine.cpp)

**Current status:** Basic skeleton with state switch  
**What it will do:** Top-level decision maker:

```
STATE_BOOT → STATE_IDLE → STATE_EXPLORING → STATE_RETURNING → STATE_FAST_RUN
     │
     ↓
  Wait for button → Start exploring maze
  At each cell: read walls, update maze map, decide next direction
  When goal found: return to start
  On second button press: fast run (optimized path)
```

#### 4.8 Maze Algorithm Files

| File | Purpose |
|---|---|
| [`flood_fill.c`](file:///c:/Users/KM Computers/OneDrive/Desktop/Projects/Maze-Runner/Full_Code/Micromouse/src/maze/flood_fill.c) | Classic flood-fill algorithm — assigns distance values to every cell, finds path to center |
| [`dijkstra_weighted.c`](file:///c:/Users/KM Computers/OneDrive/Desktop/Projects/Maze-Runner/Full_Code/Micromouse/src/maze/dijkstra_weighted.c) | Weighted shortest path — accounts for turn cost, used for fast-run optimization |
| [`solver.c`](file:///c:/Users/KM Computers/OneDrive/Desktop/Projects/Maze-Runner/Full_Code/Micromouse/src/maze/solver.c) | High-level maze solver — decides explore vs return, manages solver state |
| [`maze_explorer.cpp`](file:///c:/Users/KM Computers/OneDrive/Desktop/Projects/Maze-Runner/Full_Code/Micromouse/src/maze/maze_explorer.cpp) | Exploration logic — decides which unvisited cells to explore next |
| [`maze.h`](file:///c:/Users/KM Computers/OneDrive/Desktop/Projects/Maze-Runner/Full_Code/Micromouse/src/maze/maze.h) | 16×16 maze data structure — stores wall info for each cell |
| [`path_smoother.c`](file:///c:/Users/KM Computers/OneDrive/Desktop/Projects/Maze-Runner/Full_Code/Micromouse/src/maze/path_smoother.c) | Converts cell-by-cell path into smooth curves for fast-run |

#### 4.9 Advanced Motion Files (Fast-Run Phase)

| File | Purpose |
|---|---|
| [`motion_profile.c`](file:///c:/Users/KM Computers/OneDrive/Desktop/Projects/Maze-Runner/Full_Code/Micromouse/src/motion/motion_profile.c) | Trapezoidal & S-curve velocity profiles — controls acceleration/deceleration |
| [`arc_motion.cpp`](file:///c:/Users/KM Computers/OneDrive/Desktop/Projects/Maze-Runner/Full_Code/Micromouse/src/motion/arc_motion.cpp) | Circular arc turns — robot turns while moving forward (faster than stopping) |
| [`rolling_turn.cpp`](file:///c:/Users/KM Computers/OneDrive/Desktop/Projects/Maze-Runner/Full_Code/Micromouse/src/motion/rolling_turn.cpp) | Rolling turn coordination — blends straight segments with arc segments |
| [`s_curve.cpp`](file:///c:/Users/KM Computers/OneDrive/Desktop/Projects/Maze-Runner/Full_Code/Micromouse/src/motion/s_curve.cpp) | S-curve math — jerk-limited acceleration for ultra-smooth motion |
| [`look_ahead.cpp`](file:///c:/Users/KM Computers/OneDrive/Desktop/Projects/Maze-Runner/Full_Code/Micromouse/src/motion/look_ahead.cpp) | Plans ahead — ensures robot decelerates in time before a turn |

---

## 5. Calibration Guide

### Step-by-Step: Get Phase 5 Running Smooth

> [!IMPORTANT]
> Follow these steps **in exact order**. Do NOT skip steps. Each step depends on the previous one being correct.

---

### Step 1: Calibrate Feedforward (KV)

**What you need:** Serial Monitor, the robot on the floor

**Procedure:**
1. Temporarily bypass PID. Set motors to known PWM values and measure actual speed:

```cpp
// In Phase 5 loop, temporarily replace the drive code with:
if (p5_state == 1) {
    motor_set_both(500, 500);  // Fixed PWM, no PID
}
```

2. Read encoder speed from Serial output
3. Repeat for PWM = 500, 1000, 1500, 2000, 2500

4. Fill this table:

| PWM | Measured Speed (mm/s) | KV = PWM / Speed |
|:---:|:---:|:---:|
| 500 | ??? | ??? |
| 1000 | ??? | ??? |
| 1500 | ??? | ??? |
| 2000 | ??? | ??? |
| 2500 | ??? | ??? |

5. **Average the KV values** → that's your `FEEDFORWARD_KV`

6. Update in [speed_controller.cpp](file:///c:/Users/KM Computers/OneDrive/Desktop/Projects/Maze-Runner/Full_Code/Micromouse/src/control/speed_controller.cpp):
```cpp
#define FEEDFORWARD_KV  [your_average]
```

---

### Step 2: Fix the Low-Pass Filter

In [velocity_controller.cpp](file:///c:/Users/KM Computers/OneDrive/Desktop/Projects/Maze-Runner/Full_Code/Micromouse/src/control/velocity_controller.cpp), change:

```diff
-static LowPassFilter left_speed_filter(0.05f);
-static LowPassFilter right_speed_filter(0.05f);
+static LowPassFilter left_speed_filter(0.20f);
+static LowPassFilter right_speed_filter(0.20f);
```

**Why 0.20?** This means each new reading contributes 20% to the average. At 1kHz, the filter has a time constant of ~5ms, which is fast enough for control but smooth enough to remove the 0/1-count quantization noise.

---

### Step 3: Tune Speed PID (Start Conservative)

In [speed_controller.cpp](file:///c:/Users/KM Computers/OneDrive/Desktop/Projects/Maze-Runner/Full_Code/Micromouse/src/control/speed_controller.cpp), start with very conservative values:

```cpp
#define SPEED_KP 0.5f    // Start low
#define SPEED_KI 0.3f    // Start low
#define SPEED_KD 0.01f   // Small damping
```

**Tuning procedure:**
1. Set target speed to 150 mm/s
2. Press START → watch Serial plotter
3. **If oscillating** (speed bounces above and below target): reduce Kp
4. **If too slow to reach target** (takes > 1 second): increase Kp slightly
5. **If reaches target but sits 10 mm/s below**: increase Ki slightly
6. **If overshoots and oscillates before settling**: increase Kd slightly

```
Good PID response:           Bad PID response (shuttering):
                              
Speed ▲                       Speed ▲
      │    ┌──────────              │   /\/\/\/\/\/\/\/\
      │   /                         │  /
      │  /                          │ /
      │ /                           │/
──────┴──────────▶ Time      ──────┴──────────────────▶ Time
      smooth ramp up               violent oscillation
```

---

### Step 4: Add Serial Logging for Tuning

Add this to the Phase 5 OLED print section (inside the `millis() >= 100` block) to see PID behavior in Serial Plotter:

```cpp
Serial.print("Target:");
Serial.print(target_v);
Serial.print(",Heading_Error:");
Serial.print(target_h - fusion_get_heading());
Serial.print(",State:");
Serial.println(p5_state);
```

Open Arduino Serial Plotter (not Monitor) to see the graphs in real-time.

---

### Step 5: Calibrate Wheel Base

After the speed PID is smooth, calibrate `WHEEL_BASE_MM` for accurate turning:

1. Mark the robot's position on the floor with tape
2. Physically rotate the robot exactly 360° by hand (use a protractor or compass marks)
3. Read the heading on the OLED display
4. **If OLED shows more than 360°** (e.g., 380°): Your `WHEEL_BASE_MM` is too small → increase it
5. **If OLED shows less than 360°** (e.g., 340°): Your `WHEEL_BASE_MM` is too large → decrease it

**Formula:**
```
corrected_WHEEL_BASE = current_WHEEL_BASE × (displayed_angle / 360.0)
```

Example: If current WHEEL_BASE = 127.1 and display shows 380°:
```
corrected = 127.1 × (380 / 360) = 134.1 mm
```

Update in [robot_config.h](file:///c:/Users/KM Computers/OneDrive/Desktop/Projects/Maze-Runner/Full_Code/Micromouse/src/config/robot_config.h):
```cpp
#define WHEEL_BASE_MM  [your_corrected_value]
```

---

### Step 6: Tune Heading PID

With speed PID working smoothly and wheelbase calibrated:

1. Set heading Kp = 0.5, Ki = 0.0, Kd = 0.0
2. Drive straight → does it drift?
3. **If drifts a lot**: increase Kp to 1.0
4. **If oscillates (weaves left-right)**: decrease Kp, add Kd = 0.05
5. **If drifts slowly one way**: add small Ki = 0.01

---

### Summary: Recommended Starting Values

```cpp
// speed_controller.cpp
#define SPEED_KP 0.8f
#define SPEED_KI 0.4f
#define SPEED_KD 0.01f
#define FEEDFORWARD_KV [calibrated value from Step 1]

// heading_controller.cpp
#define HEADING_KP 0.8f
#define HEADING_KI 0.0f
#define HEADING_KD 0.05f

// velocity_controller.cpp
LowPassFilter left_speed_filter(0.20f);
LowPassFilter right_speed_filter(0.20f);
```

---

## Complete Architecture Diagram

```
┌─────────────────────────────────────────────────────────────────────┐
│                        MICROMOUSE CONTROL FLOW                       │
│                                                                      │
│  ┌──────────────┐                                                    │
│  │   BUTTONS    │──── START: toggle drive ── MODE: tune Kp           │
│  └──────────────┘                                                    │
│         │                                                            │
│  ┌──────▼──────────────────────────────────────────────────────┐     │
│  │  Main Loop (Micromouse.ino)                                  │     │
│  │  ┌──────────────────────────────────────────────────────┐   │     │
│  │  │ Sensor Update (100 Hz)                                │   │     │
│  │  │  sensor_manager_update() → reads ToF + IMU           │   │     │
│  │  └──────────────────────────────────────────────────────┘   │     │
│  │  ┌──────────────────────────────────────────────────────┐   │     │
│  │  │ Fusion Update (100 Hz)                                │   │     │
│  │  │  odometry_update() → encoder position/heading        │   │     │
│  │  │  heading_estimator_update() → fuse gyro + encoder    │   │     │
│  │  │  position_estimator_update() → best X, Y, heading    │   │     │
│  │  └──────────────────────────────────────────────────────┘   │     │
│  │  ┌──────────────────────────────────────────────────────┐   │     │
│  │  │ Motion Control (1000 Hz / 1kHz)                       │   │     │
│  │  │                                                       │   │     │
│  │  │  heading_controller_update()                          │   │     │
│  │  │       target_heading vs current_heading               │   │     │
│  │  │       → angular_velocity ω                            │   │     │
│  │  │              │                                        │   │     │
│  │  │  velocity_controller_update(linear_v, ω)              │   │     │
│  │  │       ├── differential drive mixing                   │   │     │
│  │  │       ├── read encoder deltas                         │   │     │
│  │  │       ├── low-pass filter speeds                      │   │     │
│  │  │       └── speed_controller_update()                   │   │     │
│  │  │              ├── left PID  → left PWM                 │   │     │
│  │  │              ├── right PID → right PWM                │   │     │
│  │  │              ├── add feedforward                      │   │     │
│  │  │              └── motor_set_both(left, right)          │   │     │
│  │  └──────────────────────────────────────────────────────┘   │     │
│  │  ┌──────────────────────────────────────────────────────┐   │     │
│  │  │ OLED Display (10 Hz)                                  │   │     │
│  │  │  Show state, Kp, heading                             │   │     │
│  │  └──────────────────────────────────────────────────────┘   │     │
│  └─────────────────────────────────────────────────────────────┘     │
│                                                                      │
│  ┌──────────────────────────────────────────────────────────────┐    │
│  │  FUTURE (Phase 6+)                                           │    │
│  │  cell_controller → trajectory_controller → motion_controller │    │
│  │  robot_state_machine → maze solver → flood_fill/dijkstra     │    │
│  │  wall_follower → rolling_turn → arc_motion → s_curve         │    │
│  └──────────────────────────────────────────────────────────────┘    │
└─────────────────────────────────────────────────────────────────────┘
```

---

> [!TIP]
> **The #1 thing to do right now:** Fix the low-pass filter alpha from 0.05 to 0.20 in `velocity_controller.cpp`. This single change will have the biggest impact on reducing shuttering, before you even touch PID gains.

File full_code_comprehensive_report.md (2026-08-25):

# 🧠 Micromouse Full_Code — Complete Codebase Analysis Report

> **Project**: Maze-Runner Micromouse  
> **Platform**: STM32F401CCU6 (Black Pill) @ 84 MHz, Arduino STM32 Core  
> **Language**: C/C++ (Arduino Framework)  
> **Maze**: 16×16 standard micromouse competition maze  

---

## Table of Contents

1. [The Big Picture](#1-the-big-picture)
2. [Recommended Reading Order](#2-recommended-reading-order)
3. [File-by-File Deep Dive](#3-file-by-file-deep-dive)
4. [Empty/Stub Files — Why They Exist](#4-emptystub-files--why-they-exist)
5. [How Files Interconnect](#5-how-files-interconnect)
6. [Data Flow Through the System](#6-data-flow-through-the-system)
7. [Development Phases (How the Code Was Tested)](#7-development-phases)
8. [Implementation Status Summary](#8-implementation-status-summary)

---

## 1. The Big Picture

This is the firmware for a **micromouse** — a small autonomous robot that:

1. **Explores** an unknown 16×16 maze (180mm cells) using wall sensors  
2. **Maps** the maze by recording wall positions  
3. **Solves** the shortest path from start (0,0) to the center goal (7,7)/(7,8)/(8,7)/(8,8)  
4. **Speed runs** the known path as fast as possible  

The code is organized into a **layered architecture** with 10 modules across 4 layers:

```
┌─────────────────────────────────────────────────┐
│              ROBOT LAYER (robot/)               │
│  State Machine • Mission Manager • Modes        │
├─────────────────────────────────────────────────┤
│           ALGORITHM LAYER (maze/)               │
│  Flood Fill • Dijkstra • Path Smoother • Solver │
├─────────────────────────────────────────────────┤
│         CONTROL LAYER (control/)                │
│  Motion • Heading • Speed • Velocity • PID      │
│         LOCALIZATION (localization/)             │
│  Odometry • Heading Est. • Position Est. • Pose │
├─────────────────────────────────────────────────┤
│          HARDWARE LAYER (hardware/ + sensors/)  │
│  GPIO • PWM • Motor • Encoder • Timer           │
│  MPU6050 • VL53L0X • Distance Mgr • Fusion     │
│  Battery • Button • LED                         │
├─────────────────────────────────────────────────┤
│         SUPPORT (config/ + display/ + utils/)   │
│  Pin Map • Robot Config • Algo Config           │
│  OLED • Menu • Logger • Filters • Math          │
└─────────────────────────────────────────────────┘
```

---

## 2. Recommended Reading Order

Read bottom-up: hardware first, then software that uses it.

### Phase 1: Configuration (Read These First)
| # | File | Why Read First |
|---|---|---|
| 1 | [`config.h`](file:///c:/Users/ADMIN/Desktop/Projects/Maze-Runner/Full_Code/Micromouse/src/config/config.h) | All algorithm tuning constants — maze size, costs, speeds |
| 2 | [`pin_config.h`](file:///c:/Users/ADMIN/Desktop/Projects/Maze-Runner/Full_Code/Micromouse/src/config/pin_config.h) | Every hardware pin assignment — the physical wiring map |
| 3 | [`robot_config.h`](file:///c:/Users/ADMIN/Desktop/Projects/Maze-Runner/Full_Code/Micromouse/src/config/robot_config.h) | Physical robot dimensions — wheel size, gear ratio, PWM |

### Phase 2: Hardware Abstraction Layer
| # | File | What It Teaches |
|---|---|---|
| 4 | [`gpio.h`](file:///c:/Users/ADMIN/Desktop/Projects/Maze-Runner/Full_Code/Micromouse/src/hardware/gpio.h) / [`.cpp`](file:///c:/Users/ADMIN/Desktop/Projects/Maze-Runner/Full_Code/Micromouse/src/hardware/gpio.cpp) | How motor direction pins are controlled |
| 5 | [`pwm.h`](file:///c:/Users/ADMIN/Desktop/Projects/Maze-Runner/Full_Code/Micromouse/src/hardware/pwm.h) / [`.cpp`](file:///c:/Users/ADMIN/Desktop/Projects/Maze-Runner/Full_Code/Micromouse/src/hardware/pwm.cpp) | Register-level TIM1 PWM for motor speed |
| 6 | [`motor.h`](file:///c:/Users/ADMIN/Desktop/Projects/Maze-Runner/Full_Code/Micromouse/src/hardware/motor.h) / [`.cpp`](file:///c:/Users/ADMIN/Desktop/Projects/Maze-Runner/Full_Code/Micromouse/src/hardware/motor.cpp) | High-level motor control (uses GPIO + PWM) |
| 7 | [`encoder.h`](file:///c:/Users/ADMIN/Desktop/Projects/Maze-Runner/Full_Code/Micromouse/src/hardware/encoder.h) / [`.cpp`](file:///c:/Users/ADMIN/Desktop/Projects/Maze-Runner/Full_Code/Micromouse/src/hardware/encoder.cpp) | Hardware timer encoder mode (TIM2/TIM3) |
| 8 | [`timer.h`](file:///c:/Users/ADMIN/Desktop/Projects/Maze-Runner/Full_Code/Micromouse/src/hardware/timer.h) / [`.cpp`](file:///c:/Users/ADMIN/Desktop/Projects/Maze-Runner/Full_Code/Micromouse/src/hardware/timer.cpp) | 1kHz control loop timer interrupt (TIM4) |
| 9 | [`battery.h`](file:///c:/Users/ADMIN/Desktop/Projects/Maze-Runner/Full_Code/Micromouse/src/hardware/battery.h) / [`.cpp`](file:///c:/Users/ADMIN/Desktop/Projects/Maze-Runner/Full_Code/Micromouse/src/hardware/battery.cpp) | ADC voltage monitoring with EMA filter |
| 10 | [`button.h`](file:///c:/Users/ADMIN/Desktop/Projects/Maze-Runner/Full_Code/Micromouse/src/hardware/button.h) / [`.cpp`](file:///c:/Users/ADMIN/Desktop/Projects/Maze-Runner/Full_Code/Micromouse/src/hardware/button.cpp) | Debounced button input with edge detection |
| 11 | [`led.h`](file:///c:/Users/ADMIN/Desktop/Projects/Maze-Runner/Full_Code/Micromouse/src/hardware/led.h) / [`.cpp`](file:///c:/Users/ADMIN/Desktop/Projects/Maze-Runner/Full_Code/Micromouse/src/hardware/led.cpp) | Status/debug LED with non-blocking blink |

### Phase 3: Sensors
| # | File | What It Teaches |
|---|---|---|
| 12 | [`mpu6050.h`](file:///c:/Users/ADMIN/Desktop/Projects/Maze-Runner/Full_Code/Micromouse/src/sensors/mpu6050.h) / [`.cpp`](file:///c:/Users/ADMIN/Desktop/Projects/Maze-Runner/Full_Code/Micromouse/src/sensors/mpu6050.cpp) | IMU gyro/accel I2C driver + calibration |
| 13 | [`vl53l0x.h`](file:///c:/Users/ADMIN/Desktop/Projects/Maze-Runner/Full_Code/Micromouse/src/sensors/vl53l0x.h) / [`.cpp`](file:///c:/Users/ADMIN/Desktop/Projects/Maze-Runner/Full_Code/Micromouse/src/sensors/vl53l0x.cpp) | ToF laser sensor driver (5 sensors, I2C mux) |
| 14 | [`distance_manager.h`](file:///c:/Users/ADMIN/Desktop/Projects/Maze-Runner/Full_Code/Micromouse/src/sensors/distance_manager.h) / [`.cpp`](file:///c:/Users/ADMIN/Desktop/Projects/Maze-Runner/Full_Code/Micromouse/src/sensors/distance_manager.cpp) | Wall detection logic, centering error |
| 15 | [`calibration.h`](file:///c:/Users/ADMIN/Desktop/Projects/Maze-Runner/Full_Code/Micromouse/src/sensors/calibration.h) / [`.cpp`](file:///c:/Users/ADMIN/Desktop/Projects/Maze-Runner/Full_Code/Micromouse/src/sensors/calibration.cpp) | Gyro calibration sequence at boot |
| 16 | [`sensor_manager.h`](file:///c:/Users/ADMIN/Desktop/Projects/Maze-Runner/Full_Code/Micromouse/src/sensors/sensor_manager.h) / [`.cpp`](file:///c:/Users/ADMIN/Desktop/Projects/Maze-Runner/Full_Code/Micromouse/src/sensors/sensor_manager.cpp) | Master init/update for ALL sensors |
| 17 | [`sensor_fusion.h`](file:///c:/Users/ADMIN/Desktop/Projects/Maze-Runner/Full_Code/Micromouse/src/sensors/sensor_fusion.h) / [`.cpp`](file:///c:/Users/ADMIN/Desktop/Projects/Maze-Runner/Full_Code/Micromouse/src/sensors/sensor_fusion.cpp) | Combines IMU + encoders + ToF |

### Phase 4: Localization
| # | File | What It Teaches |
|---|---|---|
| 18 | [`pose.h`](file:///c:/Users/ADMIN/Desktop/Projects/Maze-Runner/Full_Code/Micromouse/src/localization/pose.h) / [`.cpp`](file:///c:/Users/ADMIN/Desktop/Projects/Maze-Runner/Full_Code/Micromouse/src/localization/pose.cpp) | Pose struct (x, y, theta) + angle normalization |
| 19 | [`odometry.h`](file:///c:/Users/ADMIN/Desktop/Projects/Maze-Runner/Full_Code/Micromouse/src/localization/odometry.h) / [`.cpp`](file:///c:/Users/ADMIN/Desktop/Projects/Maze-Runner/Full_Code/Micromouse/src/localization/odometry.cpp) | Dead reckoning from encoder deltas |
| 20 | [`heading_estimator.h`](file:///c:/Users/ADMIN/Desktop/Projects/Maze-Runner/Full_Code/Micromouse/src/localization/heading_estimator.h) / [`.cpp`](file:///c:/Users/ADMIN/Desktop/Projects/Maze-Runner/Full_Code/Micromouse/src/localization/heading_estimator.cpp) | Complementary filter (98% gyro + 2% encoder) |
| 21 | [`position_estimator.h`](file:///c:/Users/ADMIN/Desktop/Projects/Maze-Runner/Full_Code/Micromouse/src/localization/position_estimator.h) / [`.cpp`](file:///c:/Users/ADMIN/Desktop/Projects/Maze-Runner/Full_Code/Micromouse/src/localization/position_estimator.cpp) | Fuses odometry + heading + wall corrections |
| 22 | [`coordinate_transform.h`](file:///c:/Users/ADMIN/Desktop/Projects/Maze-Runner/Full_Code/Micromouse/src/localization/coordinate_transform.h) / [`.cpp`](file:///c:/Users/ADMIN/Desktop/Projects/Maze-Runner/Full_Code/Micromouse/src/localization/coordinate_transform.cpp) | mm ↔ cell index conversion |

### Phase 5: Control System
| # | File | What It Teaches |
|---|---|---|
| 23 | [`pid.h`](file:///c:/Users/ADMIN/Desktop/Projects/Maze-Runner/Full_Code/Micromouse/src/control/pid.h) / [`.cpp`](file:///c:/Users/ADMIN/Desktop/Projects/Maze-Runner/Full_Code/Micromouse/src/control/pid.cpp) | Generic PID controller class |
| 24 | [`heading_controller.h`](file:///c:/Users/ADMIN/Desktop/Projects/Maze-Runner/Full_Code/Micromouse/src/control/heading_controller.h) / [`.cpp`](file:///c:/Users/ADMIN/Desktop/Projects/Maze-Runner/Full_Code/Micromouse/src/control/heading_controller.cpp) | PID to maintain target heading |
| 25 | [`speed_controller.h`](file:///c:/Users/ADMIN/Desktop/Projects/Maze-Runner/Full_Code/Micromouse/src/control/speed_controller.h) / [`.cpp`](file:///c:/Users/ADMIN/Desktop/Projects/Maze-Runner/Full_Code/Micromouse/src/control/speed_controller.cpp) | Per-wheel speed PID + feedforward → PWM |
| 26 | [`velocity_controller.h`](file:///c:/Users/ADMIN/Desktop/Projects/Maze-Runner/Full_Code/Micromouse/src/control/velocity_controller.h) / [`.cpp`](file:///c:/Users/ADMIN/Desktop/Projects/Maze-Runner/Full_Code/Micromouse/src/control/velocity_controller.cpp) | Unicycle (v, ω) → differential wheel speeds |
| 27 | [`motion_controller.h`](file:///c:/Users/ADMIN/Desktop/Projects/Maze-Runner/Full_Code/Micromouse/src/control/motion_controller.h) / [`.cpp`](file:///c:/Users/ADMIN/Desktop/Projects/Maze-Runner/Full_Code/Micromouse/src/control/motion_controller.cpp) | Top-level 1kHz control loop orchestrator |
| 28 | [`cell_controller.h`](file:///c:/Users/ADMIN/Desktop/Projects/Maze-Runner/Full_Code/Micromouse/src/control/cell_controller.h) / [`.cpp`](file:///c:/Users/ADMIN/Desktop/Projects/Maze-Runner/Full_Code/Micromouse/src/control/cell_controller.cpp) | Drive exactly N cells forward |
| 29 | [`turn_controller.h`](file:///c:/Users/ADMIN/Desktop/Projects/Maze-Runner/Full_Code/Micromouse/src/control/turn_controller.h) / [`.cpp`](file:///c:/Users/ADMIN/Desktop/Projects/Maze-Runner/Full_Code/Micromouse/src/control/turn_controller.cpp) | In-place and rolling (smooth) turns |
| 30 | [`wall_follower.h`](file:///c:/Users/ADMIN/Desktop/Projects/Maze-Runner/Full_Code/Micromouse/src/control/wall_follower.h) / [`.cpp`](file:///c:/Users/ADMIN/Desktop/Projects/Maze-Runner/Full_Code/Micromouse/src/control/wall_follower.cpp) | PID centering using wall sensors |
| 31 | [`trajectory_controller.h`](file:///c:/Users/ADMIN/Desktop/Projects/Maze-Runner/Full_Code/Micromouse/src/control/trajectory_controller.h) / [`.cpp`](file:///c:/Users/ADMIN/Desktop/Projects/Maze-Runner/Full_Code/Micromouse/src/control/trajectory_controller.cpp) | Motion profile tracking |

### Phase 6: Maze Algorithms
| # | File | What It Teaches |
|---|---|---|
| 32 | [`maze.h`](file:///c:/Users/ADMIN/Desktop/Projects/Maze-Runner/Full_Code/Micromouse/src/maze/maze.h) | Core data structures: Cell, MazeMap, Direction, MotionCommand |
| 33 | [`flood_fill.h`](file:///c:/Users/ADMIN/Desktop/Projects/Maze-Runner/Full_Code/Micromouse/src/maze/flood_fill.h) / [`.c`](file:///c:/Users/ADMIN/Desktop/Projects/Maze-Runner/Full_Code/Micromouse/src/maze/flood_fill.c) | BFS flood fill for search-run navigation |
| 34 | [`dijkstra_weighted.h`](file:///c:/Users/ADMIN/Desktop/Projects/Maze-Runner/Full_Code/Micromouse/src/maze/dijkstra_weighted.h) / [`.c`](file:///c:/Users/ADMIN/Desktop/Projects/Maze-Runner/Full_Code/Micromouse/src/maze/dijkstra_weighted.c) | Turn-penalized optimal path finder |
| 35 | [`path_smoother.h`](file:///c:/Users/ADMIN/Desktop/Projects/Maze-Runner/Full_Code/Micromouse/src/maze/path_smoother.h) / [`.c`](file:///c:/Users/ADMIN/Desktop/Projects/Maze-Runner/Full_Code/Micromouse/src/maze/path_smoother.c) | Waypoints → motion commands (merge straights) |
| 36 | [`solver.h`](file:///c:/Users/ADMIN/Desktop/Projects/Maze-Runner/Full_Code/Micromouse/src/maze/solver.h) / [`.c`](file:///c:/Users/ADMIN/Desktop/Projects/Maze-Runner/Full_Code/Micromouse/src/maze/solver.c) | Orchestrates flood fill + Dijkstra + smoother |
| 37 | [`maze_explorer.h`](file:///c:/Users/ADMIN/Desktop/Projects/Maze-Runner/Full_Code/Micromouse/src/maze/maze_explorer.h) / [`.cpp`](file:///c:/Users/ADMIN/Desktop/Projects/Maze-Runner/Full_Code/Micromouse/src/maze/maze_explorer.cpp) | Exploration strategy (when to return) |

### Phase 7: Robot Brain & Display
| # | File | What It Teaches |
|---|---|---|
| 38 | [`robot_state_machine.h`](file:///c:/Users/ADMIN/Desktop/Projects/Maze-Runner/Full_Code/Micromouse/src/robot/robot_state_machine.h) / [`.cpp`](file:///c:/Users/ADMIN/Desktop/Projects/Maze-Runner/Full_Code/Micromouse/src/robot/robot_state_machine.cpp) | Top-level FSM (Boot→Idle→Search→Fast) |
| 39 | [`mission_manager.h`](file:///c:/Users/ADMIN/Desktop/Projects/Maze-Runner/Full_Code/Micromouse/src/robot/mission_manager.h) / [`.cpp`](file:///c:/Users/ADMIN/Desktop/Projects/Maze-Runner/Full_Code/Micromouse/src/robot/mission_manager.cpp) | Coordinates search/optimize/fast-run |
| 40 | [`search_mode.h`](file:///c:/Users/ADMIN/Desktop/Projects/Maze-Runner/Full_Code/Micromouse/src/robot/search_mode.h) / [`.cpp`](file:///c:/Users/ADMIN/Desktop/Projects/Maze-Runner/Full_Code/Micromouse/src/robot/search_mode.cpp) | Search run behavior |
| 41 | [`fast_run_mode.h`](file:///c:/Users/ADMIN/Desktop/Projects/Maze-Runner/Full_Code/Micromouse/src/robot/fast_run_mode.h) / [`.cpp`](file:///c:/Users/ADMIN/Desktop/Projects/Maze-Runner/Full_Code/Micromouse/src/robot/fast_run_mode.cpp) | Fast speed run behavior |
| 42 | [`command_executor.h`](file:///c:/Users/ADMIN/Desktop/Projects/Maze-Runner/Full_Code/Micromouse/src/robot/command_executor.h) / [`.cpp`](file:///c:/Users/ADMIN/Desktop/Projects/Maze-Runner/Full_Code/Micromouse/src/robot/command_executor.cpp) | Executes MotionCommand sequences |
| 43 | [`competition_state.h`](file:///c:/Users/ADMIN/Desktop/Projects/Maze-Runner/Full_Code/Micromouse/src/robot/competition_state.h) / [`.cpp`](file:///c:/Users/ADMIN/Desktop/Projects/Maze-Runner/Full_Code/Micromouse/src/robot/competition_state.cpp) | Tracks runs, best time |
| 44 | [`oled_driver.h`](file:///c:/Users/ADMIN/Desktop/Projects/Maze-Runner/Full_Code/Micromouse/src/display/oled_driver.h) / [`.cpp`](file:///c:/Users/ADMIN/Desktop/Projects/Maze-Runner/Full_Code/Micromouse/src/display/oled_driver.cpp) | SSD1306 OLED display driver |
| 45 | [`menu.h`](file:///c:/Users/ADMIN/Desktop/Projects/Maze-Runner/Full_Code/Micromouse/src/display/menu.h) / [`.cpp`](file:///c:/Users/ADMIN/Desktop/Projects/Maze-Runner/Full_Code/Micromouse/src/display/menu.cpp) | Button-navigated menu |
| 46 | [`status_screen.h`](file:///c:/Users/ADMIN/Desktop/Projects/Maze-Runner/Full_Code/Micromouse/src/display/status_screen.h) / [`.cpp`](file:///c:/Users/ADMIN/Desktop/Projects/Maze-Runner/Full_Code/Micromouse/src/display/status_screen.cpp) | Standby status display |
| 47 | [`debug_screen.h`](file:///c:/Users/ADMIN/Desktop/Projects/Maze-Runner/Full_Code/Micromouse/src/display/debug_screen.h) / [`.cpp`](file:///c:/Users/ADMIN/Desktop/Projects/Maze-Runner/Full_Code/Micromouse/src/display/debug_screen.cpp) | Real-time debug screens |

### Phase 8: Main Sketch
| # | File | What It Teaches |
|---|---|---|
| 48 | [`Micromouse.ino`](file:///c:/Users/ADMIN/Desktop/Projects/Maze-Runner/Full_Code/Micromouse/Micromouse.ino) | `setup()` + `loop()` — ties everything together |

### Phase 9: Utilities
| # | File | What It Teaches |
|---|---|---|
| 49 | [`filters.h`](file:///c:/Users/ADMIN/Desktop/Projects/Maze-Runner/Full_Code/Micromouse/src/utils/filters.h) / [`.cpp`](file:///c:/Users/ADMIN/Desktop/Projects/Maze-Runner/Full_Code/Micromouse/src/utils/filters.cpp) | Low-pass EMA filter class |
| 50 | [`math_utils.h`](file:///c:/Users/ADMIN/Desktop/Projects/Maze-Runner/Full_Code/Micromouse/src/utils/math_utils.h) / [`.cpp`](file:///c:/Users/ADMIN/Desktop/Projects/Maze-Runner/Full_Code/Micromouse/src/utils/math_utils.cpp) | Constrain and map functions |
| 51 | [`logger.h`](file:///c:/Users/ADMIN/Desktop/Projects/Maze-Runner/Full_Code/Micromouse/src/utils/logger.h) / [`.cpp`](file:///c:/Users/ADMIN/Desktop/Projects/Maze-Runner/Full_Code/Micromouse/src/utils/logger.cpp) | Serial logging macros with levels |
| 52 | [`ring_buffer.h`](file:///c:/Users/ADMIN/Desktop/Projects/Maze-Runner/Full_Code/Micromouse/src/utils/ring_buffer.h) | Generic template ring buffer |
| 53 | [`serial_debug.h`](file:///c:/Users/ADMIN/Desktop/Projects/Maze-Runner/Full_Code/Micromouse/src/utils/serial_debug.h) / [`.cpp`](file:///c:/Users/ADMIN/Desktop/Projects/Maze-Runner/Full_Code/Micromouse/src/utils/serial_debug.cpp) | Serial command parser |
| 54 | [`timing.h`](file:///c:/Users/ADMIN/Desktop/Projects/Maze-Runner/Full_Code/Micromouse/src/utils/timing.h) / [`.cpp`](file:///c:/Users/ADMIN/Desktop/Projects/Maze-Runner/Full_Code/Micromouse/src/utils/timing.cpp) | Non-blocking timeout check |

---

## 3. File-by-File Deep Dive

### 3.1 Configuration Module (`src/config/`)

#### [`config.h`](file:///c:/Users/ADMIN/Desktop/Projects/Maze-Runner/Full_Code/Micromouse/src/config/config.h) — Algorithm Tuning Constants

This is the **tuneable brain** of the robot. Every competition-critical number lives here.

| Constant Group | Key Constants | Purpose |
|---|---|---|
| **Maze Geometry** | `MAZE_SIZE=16`, `CELL_SIZE_MM=180` | Standard 16×16 maze, 180mm cells |
| **Goal Cells** | `GOAL_CELLS={{7,7},{7,8},{8,7},{8,8}}` | Center 2×2 block (standard competition goal) |
| **Flood Fill** | `FLOOD_INFINITY=0xFFFF` | Sentinel for unreachable cells |
| **Dijkstra Costs** | `COST_STRAIGHT=10`, `COST_TURN_90=12`, `COST_TURN_180=30` | Turn penalties — ratio matters more than absolutes |
| **Search Speeds** | `SEARCH_MAX_SPEED=300mm/s`, `SEARCH_ACCEL=800mm/s²` | Conservative for accurate sensing |
| **Fast Speeds** | `FAST_MAX_SPEED=800mm/s`, `FAST_ACCEL=2000mm/s²` | Aggressive for competition time |
| **Turn Geometry** | `TURN_RADIUS_90=45mm`, `TURN_RADIUS_180=40mm` | Arc radii for smooth rolling turns |
| **S-Curve** | `JERK_LIMIT=8000mm/s³`, `ENABLE_S_CURVE=1` | Smooths acceleration transitions |
| **Look-Ahead** | `LOOK_AHEAD_COMMANDS=3` | Pre-plan deceleration 3 commands ahead |

#### [`pin_config.h`](file:///c:/Users/ADMIN/Desktop/Projects/Maze-Runner/Full_Code/Micromouse/src/config/pin_config.h) — Physical Wiring Map

Every pin assignment on the STM32F401CCU6. **No other file should hard-code pin numbers.**

| Hardware | Pins | Notes |
|---|---|---|
| **Left Motor** | PWM=PA9, IN1=PB15, IN2=PA10 | TIM1_CH2 |
| **Right Motor** | PWM=PA8, IN1=PB13, IN2=PB12 | TIM1_CH1 |
| **Motor STBY** | PB14 | Enable/disable motor driver |
| **Left Encoder** | PA0, PA1 | TIM2 (32-bit) |
| **Right Encoder** | PA6, PA7 | TIM3 (16-bit) |
| **I2C** | SCL=PB8, SDA=PB9 | 400kHz Fast Mode |
| **MPU6050** | I2C addr 0x68 | Shared I2C bus |
| **OLED** | I2C addr 0x3C | 128×64 SSD1306 |
| **5× ToF** | XSHUT: PA4, PB1, PC14, PA15, PB3 | Addresses: 0x30-0x34 |
| **Battery** | PB0 (ADC) | Voltage divider sense |
| **Buttons** | PB5 (Start), PB4 (Mode) | Active-LOW with pull-up |
| **LEDs** | PA5 (Status, active-HIGH), PC13 (Debug, active-LOW) | |

#### [`robot_config.h`](file:///c:/Users/ADMIN/Desktop/Projects/Maze-Runner/Full_Code/Micromouse/src/config/robot_config.h) — Physical Robot Parameters

| Parameter | Value | Derived From |
|---|---|---|
| `GEAR_RATIO` | 18.85 | Calibrated empirically (not datasheet) |
| `ENCODER_PPR` | 7 | Raw pulses per revolution |
| `ENCODER_CPR` | 7 × 18.85 × 4 = ~527.8 | Total counts per revolution |
| `WHEEL_DIAMETER` | 43mm | Measured |
| `WHEEL_CIRCUMFERENCE` | π × 43 ≈ 135.09mm | Calculated |
| `MM_PER_COUNT` | 135.09 / 527.8 ≈ 0.256mm | Distance resolution |
| `WHEEL_BASE` | 127.1mm | Calibrated from turn tests |
| `PWM_MAX` | 4199 | 84MHz / 4200 = 20kHz PWM |
| `CONTROL_LOOP_FREQ` | 1000 Hz | 1ms control period |
| **Battery** | Full=8.4V, Low=6.6V, Critical=6.0V | 2S LiPo thresholds |

---

### 3.2 Hardware Module (`src/hardware/`)

#### [`gpio.h`](file:///c:/Users/ADMIN/Desktop/Projects/Maze-Runner/Full_Code/Micromouse/src/hardware/gpio.h) / [`.cpp`](file:///c:/Users/ADMIN/Desktop/Projects/Maze-Runner/Full_Code/Micromouse/src/hardware/gpio.cpp) — Motor Direction Pin Control

**Purpose**: Isolates the TB6612FNG direction pin logic from motor.cpp.

| Function | What It Does |
|---|---|
| `gpio_init_motor_pins()` | Sets IN1/IN2/STBY as OUTPUT, enables STBY HIGH, coast mode |
| `gpio_set_standby(enable)` | HIGH = motors active, LOW = standby (power saving) |
| `gpio_set_left_direction(in1, in2)` | Writes digital values to left motor direction pins |
| `gpio_set_right_direction(in1, in2)` | Writes digital values to right motor direction pins |

#### [`pwm.h`](file:///c:/Users/ADMIN/Desktop/Projects/Maze-Runner/Full_Code/Micromouse/src/hardware/pwm.h) / [`.cpp`](file:///c:/Users/ADMIN/Desktop/Projects/Maze-Runner/Full_Code/Micromouse/src/hardware/pwm.cpp) — Register-Level TIM1 PWM

**Purpose**: 20kHz PWM on PA8 (right) and PA9 (left) using direct STM32 register access.

| Function | What It Does |
|---|---|
| `pwm_init()` | Enables GPIOA+TIM1 clocks, AF1 mode, PSC=0, ARR=4199, PWM Mode 1, MOE (mandatory for TIM1), starts counter |
| `pwm_set_left(duty)` | Writes clamped duty to TIM1→CCR1 |
| `pwm_set_right(duty)` | Writes clamped duty to TIM1→CCR2 |
| `pwm_set_both(l, r)` | Sets both simultaneously |

> [!IMPORTANT]
> TIM1 is an "advanced timer" — the `MOE` (Main Output Enable) bit in BDTR must be set, or NO PWM signal is output. This is the #1 beginner mistake with TIM1.

#### [`motor.h`](file:///c:/Users/ADMIN/Desktop/Projects/Maze-Runner/Full_Code/Micromouse/src/hardware/motor.h) / [`.cpp`](file:///c:/Users/ADMIN/Desktop/Projects/Maze-Runner/Full_Code/Micromouse/src/hardware/motor.cpp) — High-Level Motor Control

**Purpose**: Combines GPIO direction + PWM duty into a single signed-speed API.

| Function | What It Does |
|---|---|
| `motor_init()` | Calls gpio_init + standby on + motor_stop |
| `motor_set_speed(motor, pwm)` | Positive=forward, negative=reverse, 0=brake. Sets direction pins AND PWM duty |
| `motor_set_direction(motor, dir)` | TB6612 truth table: FWD=10, REV=01, BRAKE=11, COAST=00 |
| `motor_set_both(left, right)` | Convenience for differential drive |
| `motor_stop()` | Active brake (IN1=IN2=HIGH, PWM=0) |
| `motor_forward(pwm)` | Both wheels forward |
| `motor_reverse(pwm)` | Both wheels backward |
| `motor_turn_left(pwm)` | Left reverse, right forward (in-place spin) |
| `motor_turn_right(pwm)` | Left forward, right reverse |

#### [`encoder.h`](file:///c:/Users/ADMIN/Desktop/Projects/Maze-Runner/Full_Code/Micromouse/src/hardware/encoder.h) / [`.cpp`](file:///c:/Users/ADMIN/Desktop/Projects/Maze-Runner/Full_Code/Micromouse/src/hardware/encoder.cpp) — Hardware Quadrature Encoder

**Purpose**: Uses STM32 timer encoder mode — the hardware counts automatically, no ISR needed.

| Function | What It Does |
|---|---|
| `encoder_init()` | Configures TIM2 (PA0/PA1, 32-bit, AF1) and TIM3 (PA6/PA7, 16-bit, AF2) in Encoder Mode 3 (4× counting). Adds digital input filter |
| `encoder_get_count(enc)` | Reads TIMx→CNT. **Negation applied** to correct for physical wiring reversal |
| `encoder_get_delta(enc)` | Delta since last call — handles 16-bit wrap for TIM3 correctly |
| `encoder_reset(enc)` / `encoder_reset_all()` | Zeroes TIMx→CNT and internal tracking |
| `encoder_counts_to_mm(counts)` | `counts × MM_PER_COUNT` |
| `encoder_counts_to_speed(cps)` | `cps × MM_PER_COUNT` (mm/s) |
| `encoder_counts_to_rpm(cps)` | `(cps × 60) / CPR` |

> [!NOTE]
> The physical wiring is **swapped** — left encoder physically uses TIM3 and right uses TIM2. The code handles this with negation logic inside `encoder_get_count()`.

#### [`timer.h`](file:///c:/Users/ADMIN/Desktop/Projects/Maze-Runner/Full_Code/Micromouse/src/hardware/timer.h) / [`.cpp`](file:///c:/Users/ADMIN/Desktop/Projects/Maze-Runner/Full_Code/Micromouse/src/hardware/timer.cpp) — 1kHz Control Loop Timer

**Purpose**: Uses TIM4 HardwareTimer to fire a 1kHz ISR callback — the heartbeat of the control system.

| Function | What It Does |
|---|---|
| `timer_init(callback)` | Creates HardwareTimer on TIM4, sets 1000Hz, attaches ISR |
| `timer_start()` | `HardwareTimer::resume()` — starts interrupts |
| `timer_stop()` | `HardwareTimer::pause()` — stops during calibration/menu |
| `timer_tick_pending()` | Polled alternative to callback |
| `timer_tick_clear()` | Resets tick flag |
| `timer_micros()` | Wraps Arduino `micros()` (DWT cycle counter) |

> [!IMPORTANT]
> Timer allocation: TIM1 = PWM, TIM2 = Left Encoder, TIM3 = Right Encoder, **TIM4 = Control loop**. All 4 main timers are used.

#### [`battery.h`](file:///c:/Users/ADMIN/Desktop/Projects/Maze-Runner/Full_Code/Micromouse/src/hardware/battery.h) / [`.cpp`](file:///c:/Users/ADMIN/Desktop/Projects/Maze-Runner/Full_Code/Micromouse/src/hardware/battery.cpp)

| Function | What It Does |
|---|---|
| `battery_init()` | Configures ADC pin, 12-bit resolution, seeds EMA filter |
| `battery_get_voltage_mv()` | Reads ADC → pin mV → × divider ratio → EMA smooth (80/20) |
| `battery_get_percentage()` | Linear map [6000mV, 8400mV] → [0%, 100%] |
| `battery_is_low()` | < 6600mV |
| `battery_is_critical()` | < 6000mV → must stop robot |

#### [`button.h`](file:///c:/Users/ADMIN/Desktop/Projects/Maze-Runner/Full_Code/Micromouse/src/hardware/button.h) / [`.cpp`](file:///c:/Users/ADMIN/Desktop/Projects/Maze-Runner/Full_Code/Micromouse/src/hardware/button.cpp)

| Function | What It Does |
|---|---|
| `button_init()` | INPUT_PULLUP on both pins |
| `button_update()` | 20ms debounce, active-LOW detection, edge flag setting |
| `button_is_pressed(btn)` | Current debounced state |
| `button_just_pressed(btn)` | Rising edge (returns true ONCE per press, then auto-clears) |
| `button_wait_press(btn)` | Blocking wait for full press+release cycle |

#### [`led.h`](file:///c:/Users/ADMIN/Desktop/Projects/Maze-Runner/Full_Code/Micromouse/src/hardware/led.h) / [`.cpp`](file:///c:/Users/ADMIN/Desktop/Projects/Maze-Runner/Full_Code/Micromouse/src/hardware/led.cpp)

| Function | What It Does |
|---|---|
| `led_init()` | Both LEDs OUTPUT, OFF |
| `led_set(led, on)` | Direct on/off, **disables blink mode** |
| `led_toggle(led)` | Flip state |
| `led_blink(led, interval_ms)` | Non-blocking blink (0 = disable) |
| `led_update()` | Must be called in loop() — toggles based on millis() |

> [!NOTE]
> Status LED (PA5) is active-HIGH, Debug LED (PC13 onboard) is **active-LOW** — the code handles this polarity difference.

---

### 3.3 Sensors Module (`src/sensors/`)

#### [`mpu6050.h`](file:///c:/Users/ADMIN/Desktop/Projects/Maze-Runner/Full_Code/Micromouse/src/sensors/mpu6050.h) / [`.cpp`](file:///c:/Users/ADMIN/Desktop/Projects/Maze-Runner/Full_Code/Micromouse/src/sensors/mpu6050.cpp) — IMU Driver

| Function | What It Does |
|---|---|
| `mpu6050_init()` | WHO_AM_I check, wake from sleep, 1000Hz sample rate, DLPF=44Hz, gyro ±500°/s, accel ±2g |
| `mpu6050_read_raw(data)` | Burst reads 14 bytes (accel XYZ + temp + gyro XYZ) starting at register 0x3B |
| `mpu6050_read_scaled(data)` | Applies bias subtraction, scaling (16384 LSB/g, 65.5 LSB/°/s), **+2.1°/s hardware noise correction**, **0.5217× turn scaling**, and 0.85 EMA filter on Z gyro |
| `mpu6050_calibrate_gyro(samples)` | Averages N samples (default 1000) while stationary to compute zero-rate offsets |
| `mpu6050_get_gyro_bias_z()` | Returns calibrated Z bias |

> [!WARNING]
> **Hardware-specific calibration baked into code**: The `+2.1°/s` correction compensates for ToF laser current pulling the 3.3V rail. The `0.5217×` scaling corrects a 90°→172.5° over-reading. These values are specific to YOUR hardware and must be recalibrated if anything changes.

#### [`vl53l0x.h`](file:///c:/Users/ADMIN/Desktop/Projects/Maze-Runner/Full_Code/Micromouse/src/sensors/vl53l0x.h) / [`.cpp`](file:///c:/Users/ADMIN/Desktop/Projects/Maze-Runner/Full_Code/Micromouse/src/sensors/vl53l0x.cpp) — ToF Laser Sensor Driver

| Function | What It Does |
|---|---|
| `vl53l0x_init_all(sensors, count)` | **XSHUT address reassignment sequence**: all XSHUT LOW → bring up one at a time → change I2C address → start continuous mode. Uses Pololu VL53L0X library |
| `vl53l0x_start_measurement(sensor)` | No-op (continuous mode is always running) |
| `vl53l0x_read_distance_mm(sensor)` | Reads from the Pololu library. Returns 8190 on timeout/error |

#### [`distance_manager.h`](file:///c:/Users/ADMIN/Desktop/Projects/Maze-Runner/Full_Code/Micromouse/src/sensors/distance_manager.h) / [`.cpp`](file:///c:/Users/ADMIN/Desktop/Projects/Maze-Runner/Full_Code/Micromouse/src/sensors/distance_manager.cpp) — Wall Detection Logic

| Function | What It Does |
|---|---|
| `distance_manager_init()` | Populates sensor array with XSHUT/address pairs, calls `vl53l0x_init_all()` |
| `distance_manager_update()` | Reads all 5 sensors, applies EMA (70/30 blend), 8190 = invalid |
| `distance_get_mm(id)` | Raw filtered distance for any of the 5 sensors |
| `distance_has_wall_left/right/front()` | Threshold comparison (side < 120mm, front < 150mm) |
| `distance_get_centering_error()` | Both walls: R−L. One wall: compare to 50mm target. No walls: 0 |
| `distance_get_front_alignment_error()` | Front-right minus front-left (squaring up to a wall) |

#### [`calibration.h`](file:///c:/Users/ADMIN/Desktop/Projects/Maze-Runner/Full_Code/Micromouse/src/sensors/calibration.h) / [`.cpp`](file:///c:/Users/ADMIN/Desktop/Projects/Maze-Runner/Full_Code/Micromouse/src/sensors/calibration.cpp) — Boot-Time Calibration

| Function | What It Does |
|---|---|
| `calibrate_all()` | Shows "Calibrating IMU" on OLED, waits 10 seconds (hands off!), calibrates gyro, shows "Complete!" |
| `calibrate_gyro()` | Calls `mpu6050_calibrate_gyro(1000)` — ~2 seconds of sampling |
| `calibrate_distance_sensors()` | **Stub** — future implementation |
| `calibrate_encoders()` | **Stub** — future implementation |

#### [`sensor_manager.h`](file:///c:/Users/ADMIN/Desktop/Projects/Maze-Runner/Full_Code/Micromouse/src/sensors/sensor_manager.h) / [`.cpp`](file:///c:/Users/ADMIN/Desktop/Projects/Maze-Runner/Full_Code/Micromouse/src/sensors/sensor_manager.cpp) — Master Sensor Coordinator

| Function | What It Does |
|---|---|
| `sensor_manager_init()` | Calls `battery_init()`, `encoder_init()`, `mpu6050_init()`, `distance_manager_init()` |
| `sensor_manager_update()` | Calls `distance_manager_update()` (MPU6050 is read in fusion loop instead) |
| `sensor_manager_debug_print()` | Prints all 5 ToF distances + GyroZ + battery mV to Serial |

#### [`sensor_fusion.h`](file:///c:/Users/ADMIN/Desktop/Projects/Maze-Runner/Full_Code/Micromouse/src/sensors/sensor_fusion.h) / [`.cpp`](file:///c:/Users/ADMIN/Desktop/Projects/Maze-Runner/Full_Code/Micromouse/src/sensors/sensor_fusion.cpp) — Multi-Sensor Fusion

| Function | What It Does |
|---|---|
| `fusion_init()` | Initializes odometry, heading estimator, position estimator |
| `fusion_update(dt)` | (1) Update odometry from encoders, (2) Read IMU, (3) Complementary filter on heading, (4) Wall corrections on position |
| `fusion_get_heading()` | Returns fused heading in degrees |
| `fusion_reset_heading(deg)` | Forces heading — resets odometry theta and heading estimator |
| `fusion_get_velocity()` | **Returns 0.0** — not yet implemented |

---

### 3.4 Localization Module (`src/localization/`)

#### [`pose.h`](file:///c:/Users/ADMIN/Desktop/Projects/Maze-Runner/Full_Code/Micromouse/src/localization/pose.h) / [`.cpp`](file:///c:/Users/ADMIN/Desktop/Projects/Maze-Runner/Full_Code/Micromouse/src/localization/pose.cpp) — Pose Data Type

- `Pose` struct: `{x_mm, y_mm, theta_rad}`
- `pose_normalize_angle_rad(angle)` → wraps to [−π, π]
- `pose_normalize_angle_deg(angle)` → wraps to [−180, 180]

#### [`odometry.h`](file:///c:/Users/ADMIN/Desktop/Projects/Maze-Runner/Full_Code/Micromouse/src/localization/odometry.h) / [`.cpp`](file:///c:/Users/ADMIN/Desktop/Projects/Maze-Runner/Full_Code/Micromouse/src/localization/odometry.cpp) — Dead Reckoning

| Function | What It Does |
|---|---|
| `odometry_init()` | Zero pose, snapshot encoder counts |
| `odometry_update()` | Reads encoder deltas → `d_center = (L+R)/2`, `dθ = (R−L)/WHEEL_BASE` → updates x, y, θ using trigonometry |
| `odometry_get_pose()` | Current {x, y, θ} |
| `odometry_get_dtheta()` | Last computed heading change (used by heading_estimator) |
| `odometry_set_pose(new_pose)` | Force override (used by position_estimator corrections) |

#### [`heading_estimator.h`](file:///c:/Users/ADMIN/Desktop/Projects/Maze-Runner/Full_Code/Micromouse/src/localization/heading_estimator.h) / [`.cpp`](file:///c:/Users/ADMIN/Desktop/Projects/Maze-Runner/Full_Code/Micromouse/src/localization/heading_estimator.cpp) — Complementary Filter

**The key algorithm**: Fuses high-frequency gyro (accurate short-term, drifts long-term) with low-frequency encoder heading (no drift, but wheel slip causes error).

```
fused = 0.98 × (fused + gyro_dθ) + 0.02 × encoder_heading
```

**Deadband**: If encoders show no motion AND gyro rate < 1°/s → ignore gyro noise (sets dθ = 0).

#### [`position_estimator.h`](file:///c:/Users/ADMIN/Desktop/Projects/Maze-Runner/Full_Code/Micromouse/src/localization/position_estimator.h) / [`.cpp`](file:///c:/Users/ADMIN/Desktop/Projects/Maze-Runner/Full_Code/Micromouse/src/localization/position_estimator.cpp) — Full Pose Estimation

Takes odometry X/Y + fused heading, applies wall-based corrections (currently **disabled** for floor testing), and writes the corrected pose back to odometry to prevent cumulative drift.

#### [`coordinate_transform.h`](file:///c:/Users/ADMIN/Desktop/Projects/Maze-Runner/Full_Code/Micromouse/src/localization/coordinate_transform.h) / [`.cpp`](file:///c:/Users/ADMIN/Desktop/Projects/Maze-Runner/Full_Code/Micromouse/src/localization/coordinate_transform.cpp)

- `mm_to_cell(mm)` → cell index (integer division by 180)
- `cell_to_mm(cell)` → center coordinate (cell × 180 + 90)
- `get_cell_offset_mm(mm)` → distance from cell center

---

### 3.5 Control Module (`src/control/`)

#### [`pid.h`](file:///c:/Users/ADMIN/Desktop/Projects/Maze-Runner/Full_Code/Micromouse/src/control/pid.h) / [`.cpp`](file:///c:/Users/ADMIN/Desktop/Projects/Maze-Runner/Full_Code/Micromouse/src/control/pid.cpp) — Generic PID Controller

A reusable PID class used by heading, speed, and wall follower controllers.

| Method | Details |
|---|---|
| `PID(kp, ki, kd, out_min, out_max)` | Constructor with output clamping limits |
| `compute(setpoint, measurement, dt)` | P = kp × error, I = integral (anti-windup clamped), **D on measurement** (not error — prevents derivative kick), output clamped |
| `reset()` | Zeroes integral and previous values |
| `set_gains(kp, ki, kd)` | Runtime gain adjustment |

> [!TIP]
> **Derivative on measurement** instead of derivative on error is a best practice. It prevents the massive D-term spike that occurs when the setpoint suddenly changes (e.g., a step command).

#### [`heading_controller.h`](file:///c:/Users/ADMIN/Desktop/Projects/Maze-Runner/Full_Code/Micromouse/src/control/heading_controller.h) / [`.cpp`](file:///c:/Users/ADMIN/Desktop/Projects/Maze-Runner/Full_Code/Micromouse/src/control/heading_controller.cpp)

PID controller for steering. Kp=5.0, Ki=0.0, Kd=0.1. Wraps heading error to [−180, 180] before computing. Outputs angular velocity ω (clamped to ±5 rad/s).

#### [`speed_controller.h`](file:///c:/Users/ADMIN/Desktop/Projects/Maze-Runner/Full_Code/Micromouse/src/control/speed_controller.h) / [`.cpp`](file:///c:/Users/ADMIN/Desktop/Projects/Maze-Runner/Full_Code/Micromouse/src/control/speed_controller.cpp)

Two independent PID controllers (Kp=2.0, Ki=1.0, Kd=0.0) — one per wheel. Adds **feedforward** (`target_speed × 5.0`) to get close to the right PWM immediately, then PID corrects the residual error. Final output goes directly to `motor_set_both()`.

#### [`velocity_controller.h`](file:///c:/Users/ADMIN/Desktop/Projects/Maze-Runner/Full_Code/Micromouse/src/control/velocity_controller.h) / [`.cpp`](file:///c:/Users/ADMIN/Desktop/Projects/Maze-Runner/Full_Code/Micromouse/src/control/velocity_controller.cpp)

**Unicycle model conversion**: Takes (v_linear, ω_angular) and converts to differential wheel speeds:
```
v_left  = v_linear - ω × (wheel_base / 2)
v_right = v_linear + ω × (wheel_base / 2)
```
Also measures current wheel speeds from encoder deltas (× 1000 to get counts/sec from counts/ms), applies low-pass filter (α=0.05), and passes everything to speed_controller.

#### [`motion_controller.h`](file:///c:/Users/ADMIN/Desktop/Projects/Maze-Runner/Full_Code/Micromouse/src/control/motion_controller.h) / [`.cpp`](file:///c:/Users/ADMIN/Desktop/Projects/Maze-Runner/Full_Code/Micromouse/src/control/motion_controller.cpp) — **STUB**

The intended 1kHz top-level control loop. Currently all TODO — the pipeline would be:
1. `fusion_update()` → 2. `trajectory_controller_update()` → 3. `heading_controller_update()` → 4. `wall_follower_update()` → 5. `velocity_controller_update()` → 6. `speed_controller_update()`.

Phase 5 test mode in Micromouse.ino does this pipeline manually instead.

#### Remaining Control Stubs

| File | Purpose | Status |
|---|---|---|
| `cell_controller` | Drive exactly N cells | **Stub** — all TODOs |
| `turn_controller` | In-place and rolling turns | **Stub** — all TODOs |
| `wall_follower` | PID centering from wall sensors | **Stub** — all TODOs |
| `trajectory_controller` | Motion profile tracking | **Stub** — all TODOs |

---

### 3.6 Maze Algorithm Module (`src/maze/`)

#### [`maze.h`](file:///c:/Users/ADMIN/Desktop/Projects/Maze-Runner/Full_Code/Micromouse/src/maze/maze.h) — Core Data Structures

This is the **most important header** for understanding the maze logic. Everything is statically allocated.

**Direction System**:
- `Direction`: N=0, E=1, S=2, W=3 (clockwise from North)
- `WallBit`: N=0x01, E=0x02, S=0x04, W=0x08 (bitmask per cell)
- `DX[]/DY[]`: Movement deltas per direction
- `TurnType`: NONE=0, RIGHT_90=1, 180=2, LEFT_90=3
- `turn_cost_steps()`: 0 for straight, 1 for 90°, 2 for 180°

**Cell Structure** (5 bytes per cell, 1280 bytes total for 16×16):
```c
typedef struct {
    uint8_t  walls;        // Bitmask of known walls
    uint8_t  visited;      // Has robot been here?
    uint16_t flood_value;  // BFS distance to goal
} Cell;
```

**MazeMap** = 16×16 array of Cells.

**Key inline functions**:
- `maze_init_unknown()`: All cells unknown + border walls set
- `maze_set_wall()`: Sets wall on BOTH sides (cell + neighbor)
- `maze_has_wall()`: Check wall bitmask
- `maze_in_bounds()`: Bounds check

**Motion Commands** (output of path smoother):
- `CMD_STRAIGHT`, `CMD_TURN_LEFT_90`, `CMD_TURN_RIGHT_90`, `CMD_TURN_180`
- `CMD_SMOOTH_LEFT_90`, `CMD_SMOOTH_RIGHT_90` (rolling turns)
- `CMD_SS_LEFT_90`, `CMD_SS_RIGHT_90` (compound: straight + smooth turn)

#### [`flood_fill.h`](file:///c:/Users/ADMIN/Desktop/Projects/Maze-Runner/Full_Code/Micromouse/src/maze/flood_fill.h) / [`.c`](file:///c:/Users/ADMIN/Desktop/Projects/Maze-Runner/Full_Code/Micromouse/src/maze/flood_fill.c) — BFS Search Algorithm

**Tier 1** algorithm for the search run (exploring unknown maze).

- `flood_fill_compute()`: Multi-source BFS from goal cells. Seeds goals with distance 0, expands outward. O(256) cells, < 10µs on Cortex-M4.
- `flood_fill_choose_direction()`: Picks neighbor with lowest flood value. **Preference order**: straight → left → right → reverse (reduces unnecessary turns).

#### [`dijkstra_weighted.h`](file:///c:/Users/ADMIN/Desktop/Projects/Maze-Runner/Full_Code/Micromouse/src/maze/dijkstra_weighted.h) / [`.c`](file:///c:/Users/ADMIN/Desktop/Projects/Maze-Runner/Full_Code/Micromouse/src/maze/dijkstra_weighted.c) — Optimal Path Finder

**Tier 2** algorithm for the fast run. State = (x, y, heading), 1024 total states. Uses a **fixed-size binary min-heap** as priority queue. Penalizes turns: a longer path with fewer turns can be faster.

#### [`path_smoother.h`](file:///c:/Users/ADMIN/Desktop/Projects/Maze-Runner/Full_Code/Micromouse/src/maze/path_smoother.h) / [`.c`](file:///c:/Users/ADMIN/Desktop/Projects/Maze-Runner/Full_Code/Micromouse/src/maze/path_smoother.c) — Command Optimizer

**Tier 3**: Converts raw waypoints into compact motion commands. Merges consecutive same-direction moves into `CMD_STRAIGHT(n)`, classifies turns, detects diagonals.

#### [`solver.h`](file:///c:/Users/ADMIN/Desktop/Projects/Maze-Runner/Full_Code/Micromouse/src/maze/solver.h) / [`.c`](file:///c:/Users/ADMIN/Desktop/Projects/Maze-Runner/Full_Code/Micromouse/src/maze/solver.c) — Top-Level Orchestrator

| Function | What It Does |
|---|---|
| `solver_init(s)` | Unknown maze, position (0,0), heading North, search mode |
| `solver_record_walls(s, front, left, right)` | Converts relative sensor readings (front/left/right) to absolute wall directions and records in maze |
| `solver_search_step(s)` | Recomputes flood fill → returns best direction |
| `solver_advance(s, dir)` | Moves mouse position in maze + marks cell visited |
| `solver_at_goal(s)` / `solver_at_start(s)` | Position checks |
| `solver_compute_fast_path(s, x, y, heading)` | Runs Dijkstra → path_smooth → stores commands |
| `solver_get_next_command(s)` | Returns next MotionCommand (NULL when done) |

#### [`maze_explorer.h`](file:///c:/Users/ADMIN/Desktop/Projects/Maze-Runner/Full_Code/Micromouse/src/maze/maze_explorer.h) / [`.cpp`](file:///c:/Users/ADMIN/Desktop/Projects/Maze-Runner/Full_Code/Micromouse/src/maze/maze_explorer.cpp) — **Stub**

Decides when to stop exploring and return to start. All TODOs.

---

### 3.7 Robot Module (`src/robot/`)

#### [`robot_state_machine.h`](file:///c:/Users/ADMIN/Desktop/Projects/Maze-Runner/Full_Code/Micromouse/src/robot/robot_state_machine.h) / [`.cpp`](file:///c:/Users/ADMIN/Desktop/Projects/Maze-Runner/Full_Code/Micromouse/src/robot/robot_state_machine.cpp)

States: `BOOT → IDLE → CALIBRATING → SEARCH_RUN → RETURN_START → FAST_RUN → ERROR`

Currently a minimal skeleton — `fsm_update()` has empty `case` handlers.

#### Other Robot Files

| File | Purpose | Status |
|---|---|---|
| `mission_manager` | Coordinates search → optimize → fast run strategy | **Stub** |
| `search_mode` | Per-cell search behavior (calls solver) | **Stub** |
| `fast_run_mode` | Executes precomputed fast path | **Stub** |
| `command_executor` | Iterates through MotionCommand array | **Stub** |
| `competition_state` | Tracks run count, best time | **Stub** |

---

### 3.8 Display Module (`src/display/`)

#### [`oled_driver.h`](file:///c:/Users/ADMIN/Desktop/Projects/Maze-Runner/Full_Code/Micromouse/src/display/oled_driver.h) / [`.cpp`](file:///c:/Users/ADMIN/Desktop/Projects/Maze-Runner/Full_Code/Micromouse/src/display/oled_driver.cpp) — ✅ Fully Implemented

Uses Adafruit_SSD1306 library. `oled_init()`, `oled_clear()`, `oled_update()`, `oled_print(x, y, text)`. `oled_draw_maze()` is a stub.

#### Other Display Files — All Stubs

`menu`, `status_screen`, `debug_screen` — all have headers defined but implementation is TODO.

---

### 3.9 Utils Module (`src/utils/`)

| File | What It Provides | Status |
|---|---|---|
| `filters.h/.cpp` | `LowPassFilter` class (EMA: `new = α×input + (1-α)×prev`) | ✅ Implemented |
| `math_utils.h/.cpp` | `math_constrain()`, `math_map()` | ✅ Implemented |
| `logger.h/.cpp` | `LOG_INFO()`, `LOG_DEBUG()`, `LOG_WARN()`, `LOG_ERROR()` macros (level-filtered Serial.printf) | ✅ Implemented |
| `ring_buffer.h` | Template-based circular buffer with push/pop/full/empty | ✅ Implemented (header-only) |
| `serial_debug.h/.cpp` | Serial command parser | **Stub** |
| `timing.h/.cpp` | `time_is_expired(start, duration)` — non-blocking timeout | ✅ Implemented |

---

### 3.10 Motion Module (`src/motion/`) — All Stubs

These files define future motion primitives but have only headers or minimal stubs:

| File | Purpose | Status |
|---|---|---|
| `motion_profile.h/.c` | Trapezoidal/S-curve velocity profiles | Has header with types defined |
| `straight_motion.h/.cpp` | Drive a fixed distance with profile | **Stub** |
| `arc_motion.h/.cpp` | Constant-radius arc (rolling turns) | **Stub** |
| `rolling_turn.h/.cpp` | Smooth turn while moving | **Stub** |
| `s_curve.h/.cpp` | S-curve jerk-limited acceleration | **Stub** |
| `look_ahead.h/.cpp` | Pre-plan deceleration for upcoming turns | **Stub** |

---

## 4. Empty/Stub Files — Why They Exist

> [!IMPORTANT]
> **None of the files are truly "empty"** — they all have headers with function declarations and `.cpp` files with function bodies (even if just `{ /* TODO */ }`). This is intentional **software architecture scaffolding**.

### Why This Pattern Matters

1. **Compiles without errors**: Every `#include` resolves. Every function call has a definition (even if it does nothing). The project builds and runs the implemented phases.

2. **Module boundaries are locked**: The headers define the **API contract** between modules. When you implement `wall_follower_update()`, you know exactly what parameters it takes and what it returns — because the header was designed upfront.

3. **Incremental development**: The project uses a **phased testing approach** (Phase 1→5 test modes in Micromouse.ino). Each phase only needs a subset of modules. Stubs let unused modules exist without blocking.

4. **Dependency graph is complete**: Even `cell_controller.cpp` (a stub) correctly includes the headers it will need, so the full dependency tree is visible.

### Files That Are Stubs But Critical for the Final Product

| Stub File | Why It's Needed |
|---|---|
| `motion_controller.cpp` | Will be the 1kHz ISR callback that chains ALL controllers |
| `cell_controller.cpp` | Will track distance traveled and trigger deceleration at cell boundary |
| `turn_controller.cpp` | Will execute 90°/180° turns using heading_controller |
| `wall_follower.cpp` | Will add centering corrections during straight moves |
| `trajectory_controller.cpp` | Will follow motion profiles (trapezoidal/S-curve) |
| `search_mode.cpp` | Will call solver_search_step() + physical movements |
| `fast_run_mode.cpp` | Will iterate solver_get_next_command() |
| `mission_manager.cpp` | Will orchestrate: Search → Return → Fast Run → Repeat |
| `robot_state_machine.cpp` | Will transition states based on button presses and goal detection |
| `menu.cpp` | Will let the user select Search/Fast/Calibrate via buttons+OLED |

---

## 5. How Files Interconnect

### Dependency Diagram (Simplified)

```mermaid
graph TD
    INO[Micromouse.ino] --> HW[hardware/]
    INO --> SENS[sensors/]
    INO --> LOC[localization/]
    INO --> CTRL[control/]
    INO --> ROBOT[robot/]
    INO --> DISP[display/]
    INO --> UTIL[utils/]
    
    HW --> CFG[config/]
    SENS --> HW
    SENS --> CFG
    LOC --> SENS
    LOC --> HW
    LOC --> CFG
    CTRL --> LOC
    CTRL --> HW
    CTRL --> SENS
    CTRL --> MAZE[maze/]
    CTRL --> UTIL
    ROBOT --> MAZE
    ROBOT --> CTRL
    DISP --> HW
    
    MAZE --> CFG
```

### Key Interconnection Chains

**Chain 1: Sensor → Fusion → Localization → Control → Motor**
```
VL53L0X / MPU6050 → sensor_manager_update() → fusion_update() 
→ odometry_update() → heading_estimator_update() → position_estimator_update()
→ heading_controller_update() → velocity_controller_update() → speed_controller_update() 
→ motor_set_both()
```

**Chain 2: Sensor → Maze → Solver → Commands**
```
distance_has_wall_front/left/right() → solver_record_walls() → flood_fill_compute()
→ solver_search_step() → return Direction → physical move
```

**Chain 3: Solver → Fast Path → Executor → Motion**
```
solver_compute_fast_path() → dijkstra_compute() → path_smooth() → SmoothedPath
→ solver_get_next_command() → motion_execute_command() → cell_controller/turn_controller
```

---

## 6. Data Flow Through the System

### Every 1ms (Control Loop @ 1kHz)

```
┌─ Encoder Hardware (TIM2/TIM3) ──┐
│  Counts automatically at 4×     │
│  resolution — no CPU needed     │
└─────────────┬───────────────────┘
              │ encoder_get_delta()
              ▼
┌─ Odometry ──────────────────────┐
│  dL, dR → d_center, dθ         │
│  Update (x, y, θ)              │
└─────────────┬───────────────────┘
              │ odometry_get_dtheta()
              ▼
┌─ Heading Estimator ─────────────┐
│  98% × (fused + gyro_dθ)       │ ◄── MPU6050 gyro_z_dps
│  + 2% × encoder_heading        │
└─────────────┬───────────────────┘
              │ heading_estimator_get()
              ▼
┌─ Heading Controller (PID) ──────┐
│  error = target_heading - fused │
│  → angular velocity ω          │
└─────────────┬───────────────────┘
              │ ω (rad/s)
              ▼
┌─ Velocity Controller ──────────┐
│  v_left  = v - ω×(base/2)     │
│  v_right = v + ω×(base/2)     │
└─────────────┬───────────────────┘
              │ target wheel speeds
              ▼
┌─ Speed Controller (2× PID) ────┐
│  FF + PID per wheel → PWM      │
└─────────────┬───────────────────┘
              │ motor_set_both(L, R)
              ▼
┌─ Motor Driver (TB6612FNG) ─────┐
│  Direction pins + TIM1 PWM     │
└─────────────────────────────────┘
```

### Every ~10ms (Sensor Update)

```
┌─ VL53L0X (5 sensors) ──────────┐
│  Continuous mode I2C reads      │
│  EMA filtered (70/30)          │
└─────────────┬───────────────────┘
              │ distance_get_mm()
              ▼
┌─ Wall Detection ────────────────┐
│  Front < 150mm? Left < 120mm?  │
│  Centering error = R - L       │
└─────────────────────────────────┘
```

### Per Cell (Search Run)

```
Robot enters new cell
    │
    ▼
Read walls (front/left/right from sensors)
    │
    ▼
solver_record_walls() → updates MazeMap
    │
    ▼
flood_fill_compute() → recompute all distances
    │
    ▼
flood_fill_choose_direction() → next Direction
    │
    ▼
Turn if needed → drive one cell → solver_advance()
    │
    ▼
At goal? → solver_compute_fast_path()
```

---

## 7. Development Phases

The `Micromouse.ino` file has **5 test phase modes** controlled by `#define PHASE_X_TEST_MODE`:

| Phase | What It Tests | Modules Used |
|---|---|---|
| **Phase 1** | GPIO, buttons, LEDs, OLED, battery, timer heartbeat | gpio, button, led, battery, timer, oled_driver |
| **Phase 2** | Motors (forward/reverse/turn), encoders (count/speed/distance) | + motor, pwm, encoder |
| **Phase 3** | IMU (gyro Z), ToF sensors (5 distances), calibration | + mpu6050, vl53l0x, distance_manager, calibration, sensor_manager |
| **Phase 4** | Sensor fusion, odometry, heading estimation (X/Y/θ tracking) | + sensor_fusion, odometry, heading_estimator, position_estimator |
| **Phase 5** | PID control: drive straight, turn 90° | + heading_controller, velocity_controller, speed_controller, pid |

> [!NOTE]
> Currently **Phase 5** is active (`PHASE_5_TEST_MODE 1`). The robot can drive straight at 150mm/s while maintaining heading, and turn 90° on button press.

---

## 8. Implementation Status Summary

### ✅ Fully Implemented (Working)

| Module | Files | Tested In |
|---|---|---|
| **Config** | config.h, pin_config.h, robot_config.h | All phases |
| **GPIO** | gpio.h/.cpp | Phase 1+ |
| **PWM** | pwm.h/.cpp (register-level) | Phase 2+ |
| **Motor** | motor.h/.cpp | Phase 2+ |
| **Encoder** | encoder.h/.cpp (register-level) | Phase 2+ |
| **Timer** | timer.h/.cpp (TIM4 HardwareTimer) | Phase 1+ |
| **Battery** | battery.h/.cpp (ADC + EMA) | Phase 1+ |
| **Button** | button.h/.cpp (debounce + edge) | Phase 1+ |
| **LED** | led.h/.cpp (blink + active-low) | Phase 1+ |
| **MPU6050** | mpu6050.h/.cpp (I2C + calibration) | Phase 3+ |
| **VL53L0X** | vl53l0x.h/.cpp (Pololu library) | Phase 3+ |
| **Distance Manager** | distance_manager.h/.cpp | Phase 3+ |
| **Calibration** | calibration.h/.cpp | Phase 3+ |
| **Sensor Manager** | sensor_manager.h/.cpp | Phase 3+ |
| **Sensor Fusion** | sensor_fusion.h/.cpp | Phase 4+ |
| **Odometry** | odometry.h/.cpp | Phase 4+ |
| **Heading Estimator** | heading_estimator.h/.cpp | Phase 4+ |
| **Position Estimator** | position_estimator.h/.cpp | Phase 4+ |
| **Coordinate Transform** | coordinate_transform.h/.cpp | Phase 4+ |
| **Pose** | pose.h/.cpp | Phase 4+ |
| **PID** | pid.h/.cpp | Phase 5 |
| **Heading Controller** | heading_controller.h/.cpp | Phase 5 |
| **Speed Controller** | speed_controller.h/.cpp | Phase 5 |
| **Velocity Controller** | velocity_controller.h/.cpp | Phase 5 |
| **OLED Driver** | oled_driver.h/.cpp | Phase 1+ |
| **Utils** | filters, math_utils, logger, ring_buffer, timing | Various |

### ✅ Implemented (Algorithm — Not Yet Connected to Hardware)

| Module | Files | Notes |
|---|---|---|
| **Maze Data Structures** | maze.h | Complete — walls, cells, directions, commands |
| **Flood Fill** | flood_fill.h/.c | Complete — BFS with straight preference |
| **Dijkstra** | dijkstra_weighted.h/.c | Complete — turn-penalized pathfinding |
| **Path Smoother** | path_smoother.h/.c | Complete — command merging and classification |
| **Solver** | solver.h/.c | Complete — orchestrates all 3 tiers |

### ⬜ Stub (API Defined, Implementation TODO)

| Module | Files | What's Missing |
|---|---|---|
| **Motion Controller** | motion_controller.h/.cpp | The 1kHz pipeline orchestration |
| **Cell Controller** | cell_controller.h/.cpp | Distance tracking for cell traversal |
| **Turn Controller** | turn_controller.h/.cpp | Turn execution logic |
| **Wall Follower** | wall_follower.h/.cpp | Centering PID from wall sensors |
| **Trajectory Controller** | trajectory_controller.h/.cpp | Motion profile following |
| **Motion Profiles** | motion_profile.h/.c | Trapezoidal/S-curve generators |
| **Straight Motion** | straight_motion.h/.cpp | Fixed-distance drive |
| **Arc Motion** | arc_motion.h/.cpp | Constant-radius curves |
| **Rolling Turn** | rolling_turn.h/.cpp | Turn-while-moving |
| **S-Curve** | s_curve.h/.cpp | Jerk-limited profiles |
| **Look-Ahead** | look_ahead.h/.cpp | Pre-plan deceleration |
| **Robot FSM** | robot_state_machine.h/.cpp | State transition logic |
| **Mission Manager** | mission_manager.h/.cpp | Search/fast run coordination |
| **Search Mode** | search_mode.h/.cpp | Per-cell search behavior |
| **Fast Run Mode** | fast_run_mode.h/.cpp | Precomputed path execution |
| **Command Executor** | command_executor.h/.cpp | MotionCommand iteration |
| **Competition State** | competition_state.h/.cpp | Run tracking |
| **Maze Explorer** | maze_explorer.h/.cpp | Exploration strategy |
| **Menu** | menu.h/.cpp | Button UI |
| **Status Screen** | status_screen.h/.cpp | Standby display |
| **Debug Screen** | debug_screen.h/.cpp | Runtime debug screens |
| **Serial Debug** | serial_debug.h/.cpp | Command parser |

---

> [!TIP]
> **The next step** to complete this robot is to implement `motion_controller_update()` — wiring together the already-working PID controllers (Phase 5) with the already-working maze solver into an automated cell-by-cell exploration loop. The hardest part (hardware drivers, sensors, PID tuning, maze algorithms) is already done.

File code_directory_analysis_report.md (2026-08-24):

# Micromouse Code Directory Analysis Report

This report analyzes the entire `Maze-Runner/Full_Code/Micromouse` codebase, detailing the purpose of each directory and the use cases of all source files within them. The code follows a clean, modular architecture, splitting responsibilities across different specialized modules inside the `src/` directory.

## 📁 Root Directory
Contains the core project file and high-level project folders.
- **`Micromouse.ino`**: The main Arduino sketch file. It contains the `setup()` and `loop()` functions, acting as the entry point that initializes all hardware and starts the high-level robot state machine.
- **`docs/`**: Documentation files for the project.
- **`examples/`**: Example scripts or sub-projects.
- **`tests/`**: Unit tests or test scripts.
- **`src/`**: Contains the entirety of the robot's modular C/C++ source code.

---

## 📁 `src/config/`
Stores global configurations, tunings, and hardware pin mappings.
- **`config.h`**: General global configuration variables and compiler flags.
- **`pin_config.h`**: Maps microcontroller pins to specific hardware peripherals (e.g., motors, sensors, LEDs).
- **`robot_config.h`**: Contains physical robot parameters (e.g., wheel diameter, track width) and high-level tunings.

---

## 📁 `src/control/`
Implements the closed-loop control algorithms that drive the robot accurately.
- **`cell_controller`**: Manages alignment and navigation strictly within a single maze cell.
- **`heading_controller`**: Keeps the robot pointing at the correct angle using gyroscope feedback.
- **`motion_controller`**: High-level coordinator that translates pathing commands into target speeds and headings.
- **`pid`**: A generic Proportional-Integral-Derivative (PID) controller implementation used by the other controllers.
- **`speed_controller`**: Ensures the wheels spin at the target velocities using encoder feedback.
- **`trajectory_controller`**: Calculates the precise paths (trajectories) the robot must follow dynamically.
- **`turn_controller`**: Specifically handles in-place or moving turns accurately.
- **`velocity_controller`**: An abstraction for overall forward and angular velocity targets.
- **`wall_follower`**: Adjusts the robot's heading to stay perfectly centered between maze walls using side distance sensors.

---

## 📁 `src/display/`
Manages the user interface via an onboard OLED screen.
- **`debug_screen`**: Renders raw sensor data and internal state for debugging purposes.
- **`menu`**: Provides an interactive menu system to select modes (Search, Fast Run, Calibrate).
- **`oled_driver`**: Low-level wrapper around the Adafruit SSD1306 OLED library for drawing primitives.
- **`status_screen`**: Displays high-level status (battery voltage, current mode, time).

---

## 📁 `src/hardware/`
Low-level hardware abstraction layer (HAL) for microcontroller peripherals.
- **`battery`**: Reads the battery voltage via an ADC pin to prevent over-discharge.
- **`button`**: Handles user input buttons with debouncing logic.
- **`buzzer`**: Controls the piezo buzzer for audio feedback/beeps.
- **`encoder`**: Reads the quadrature encoders on the wheels to track physical distance traveled.
- **`gpio`**: Wrapper for standard General Purpose Input/Output operations.
- **`led`**: Controls status LEDs (blinking, toggling).
- **`motor`**: Translates target speeds into PWM signals for the motor drivers.
- **`pwm`**: Low-level hardware timer configurations for generating Pulse Width Modulation signals.
- **`timer`**: Configures hardware timers and interrupts used for the main control loops.

---

## 📁 `src/localization/`
Tracks the robot's position and orientation in physical space.
- **`coordinate_transform`**: Converts between global maze coordinates and local robot coordinates.
- **`heading_estimator`**: Integrates gyroscope data to determine the robot's current angle.
- **`odometry`**: Calculates absolute position (X, Y, Theta) based on wheel encoder ticks.
- **`pose`**: Defines the data structures for representing a spatial Pose.
- **`position_estimator`**: Combines odometry and wall-sensing to produce a highly accurate estimate of the robot's location.

---

## 📁 `src/maze/`
The "brain" of the mouse containing maze-solving and pathfinding algorithms.
- **`dijkstra_weighted`**: Pathfinding algorithm used to find the shortest/fastest route through the known maze, factoring in turn costs.
- **`flood_fill`**: Algorithm used to explore the maze and find the center by updating distances to the goal.
- **`maze.h`**: Data structures representing the 16x16 grid, wall definitions, and cell states.
- **`maze_explorer`**: Logic that dictates how the robot explores unknown cells.
- **`path_smoother`**: Optimizes step-by-step paths (e.g. forward, turn right, forward) into smooth, continuous curves (e.g. diagonal runs).
- **`solver`**: The overarching solver that manages the known map and requests paths to the center or back to start.

---

## 📁 `src/motion/`
Generates smooth velocity and acceleration profiles to prevent the tires from slipping.
- **`arc_motion`**: Calculates wheel speeds for driving in curved arcs.
- **`look_ahead`**: Advanced algorithm that looks ahead at upcoming corners to pre-calculate deceleration.
- **`motion_profile`**: Generates smooth acceleration/deceleration trapezoidal or S-curve velocity targets.
- **`rolling_turn`**: Logic for executing high-speed, smooth turns without stopping.
- **`s_curve`**: A jerk-limited velocity profile generator for even smoother acceleration.
- **`straight_motion`**: Profile for moving perfectly straight between cells.

---

## 📁 `src/robot/`
High-level state machines that tie everything together into autonomous behaviors.
- **`command_executor`**: Translates solver directions (North, South, East, West) into physical motion commands (Forward, Turn Right).
- **`competition_state`**: Tracks overall run times and competition metrics.
- **`fast_run_mode`**: The behavior mode used when the maze is solved and the robot dashes to the center as fast as possible.
- **`mission_manager`**: Coordinates switching between exploration, returning to start, and fast runs.
- **`robot_state_machine`**: The overarching state machine (Init -> Idle -> Search -> Fast Run -> Error).
- **`search_mode`**: The behavior mode used for methodically exploring the maze and discovering walls.

---

## 📁 `src/sensors/`
Abstractions for reading and processing raw sensor data.
- **`calibration`**: Routines to calibrate the gyro offsets and distance sensor baselines.
- **`distance_manager`**: High-level interface for reading all distance sensors collectively.
- **`mpu6050`**: I2C driver for the MPU6050 IMU (gyroscope and accelerometer).
- **`sensor_fusion`**: Fuses data from multiple sensors (IMU + Encoders) for better accuracy.
- **`sensor_manager`**: Initializes and polls all sensors at a fixed frequency.
- **`vl53l0x`**: I2C driver for the VL53L0X Time-of-Flight laser distance sensors used for wall detection.

---

## 📁 `src/utils/`
Helper functions, math routines, and generic utilities.
- **`filters`**: Software filters (e.g., low-pass, moving average) to smooth out noisy sensor data.
- **`logger`**: System for logging errors and events.
- **`math_utils`**: Common math functions, angle normalization, and fast approximations.
- **`ring_buffer`**: A circular buffer implementation used for storing streams of data or UART packets.
- **`serial_debug`**: Wraps `Serial.print` functions for printing formatted debug text to a PC over USB.
- **`timing`**: Functions for non-blocking delays and tracking execution time limits.

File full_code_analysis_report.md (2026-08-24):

# 🔬 Full_Code — Complete Function-by-Function Analysis Report

> **Project:** Maze-Runner Micromouse  
> **Scope:** Every file in `Full_Code/Micromouse/src/` — 67 files across 10 modules  
> **Date:** 2026-08-24

---

## 📁 Project Structure Overview

```
Micromouse/
├── Micromouse.ino              ← Main entry point (setup + loop + phase tests)
└── src/
    ├── config/                 ← Constants & pin assignments (3 files)
    ├── hardware/               ← Motor, encoder, PWM, GPIO, buttons, LEDs, battery, timer (16 files)
    ├── sensors/                ← MPU6050, VL53L0X, distance manager, fusion, calibration (12 files)
    ├── localization/           ← Odometry, heading estimator, position estimator, pose (10 files)
    ├── control/                ← PID, speed/heading/velocity/cell/turn/wall controllers (18 files)
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

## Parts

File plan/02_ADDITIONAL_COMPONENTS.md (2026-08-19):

# 02 — Additional Components You MUST Have
## Parts Missing from Your Current List

---

## 🔴 Critical Missing Parts

### 1. Voltage Regulators (REQUIRED)
Your 7.4V battery cannot power STM32 or sensors directly.

| Part | Converts | Supplies | Why |
|---|---|---|-----|
| **MP1584 or LM2596 Buck Module** | 7.4V → 5V | STM32 VIN | Efficient step-down |
| **AMS1117-3.3 LDO** | 5V → 3.3V | VL53L0X, MPU6050 | Low dropout, 800mA |

> [!TIP]
> Alternatively: Use a single **MP2307** or **XL4005** buck converter set to 5V, and use STM32's onboard 3.3V regulator for sensors (max ~150mA — check if enough for 5 VL53L0X + MPU6050).

**Total 3.3V current needed:**
- 5× VL53L0X: 5 × 19mA = 95mA
- 1× MPU6050: 3.9mA
- **Total: ~100mA** → STM32 onboard 3.3V regulator is okay if < 150mA limit

---

### 2. Decoupling Capacitors (REQUIRED)
Without these, your motors will cause noise that crashes sensors.

| Value | Qty | Placement |
|---|-----|---|
| 100µF electrolytic | 2 | Across motor power supply (VM pin of TB6612FNG) |
| 100nF ceramic (0.1µF) | 6 | Across each IC's VCC/GND pins |
| 10µF electrolytic | 2 | Across 5V and 3.3V regulator outputs |

---

### 3. Wheels + Chassis (REQUIRED)
- **Wheels:** 30–40mm diameter rubber wheels for N20 motors (check your motor shaft = 3mm D-shaft)
- **Chassis:** Custom PCB chassis OR laser-cut acrylic 100×100mm
- **Motor mounts:** Brass standoffs or N20 motor brackets

---

### 4. Ball Caster (REQUIRED)
- **10mm metal or nylon ball caster** — provides 3rd contact point for stability
- Without this, your robot will tip forward/backward
- Alternative: PTFE (Teflon) skid pad for lighter weight

---

### 5. Connectors (REQUIRED)
- **XT30 connector pair** — for battery connection (rated 30A, compact)
- **JST-PH 2.0mm connectors** — for motor and sensor harnesses (easy disconnect)
- **2.54mm pin headers + female sockets** — for STM32 breadboard/PCB mounting

> [!TIP]
> Use connectors everywhere — never solder wires directly. This lets you swap components without desoldering.

---

### 6. XSHUT Control Resistors (REQUIRED for VL53L0X)
- 5× **10kΩ resistors** as pull-ups on XSHUT lines (or use internal STM32 pull-ups)

---

### 7. ST-Link V2 Programmer (REQUIRED)
- Arduino IDE cannot upload to STM32 via USB without a bootloader
- **ST-Link V2** (~$2 clone) is essential for flashing
- Or use: USB-to-Serial + STM32 BOOT0 bootloader method

---

### 8. Logic Level Shifter (SOMETIMES NEEDED)
- VL53L0X is 2.8V–3.3V I2C
- STM32 I2C is 3.3V
- **Usually compatible directly** — but if sensors glitch, add a level shifter
- Recommended: **BSS138-based bidirectional I2C level shifter**

---

## 🟡 Strongly Recommended Parts

### 9. LiPo Battery Protection/BMS
- 2S BMS module with overcharge, overdischarge, and short circuit protection
- Protects your cells from damage
- Includes balance charging port

### 10. LiPo Charger
- **TP4056-based 2S charger** or **B3AC compact balance charger**
- Never charge LiPo without a proper charger — fire hazard!

### 11. Power Switch + LED Indicator
- SPDT or DPDT toggle switch (2A rated)
- Red LED + 330Ω resistor for power indicator
- Green LED + 330Ω for status/maze-running indicator

### 12. Buttons
- **2× tactile push buttons**:
  - Button 1: Start/stop maze run
  - Button 2: Reset / return to start

### 13. OLED Display (Optional)
- **0.96" SSD1306 I2C OLED**
- Shows: cell position, heading, sensor values during debug
- Very useful during development

---

## 🟢 Nice to Have

### 14. Logic Analyzer
- **8-channel logic analyzer** (~$5 clone)
- Essential for debugging I2C, encoder signals, PWM
- Works with PulseView (free software)

### 15. Multimeter
- For voltage checking, continuity testing

### 16. Hot Glue / Kapton Tape
- Secure sensors at correct angles
- Insulate bare solder joints

### 17. HC-05 Bluetooth Module (for wireless debugging)
- Stream sensor data and PID values to laptop in real-time
- Remotely start/stop runs
- ~$2–3 cost, massive time savings during tuning

---

## 📦 Full Shopping List Summary

```
CRITICAL:
[ ] MP1584 buck converter (5V output)          Search: "MP1584 adjustable buck converter"
[ ] AMS1117-3.3 LDO regulator                  Search: "AMS1117 3.3V module"
[ ] 100µF capacitors ×4                        Search: "100uF 16V electrolytic capacitor"
[ ] 100nF capacitors ×10                       Search: "100nF ceramic capacitor 0.1uF"
[ ] Rubber wheels 34mm ×2 (fits 3mm D-shaft)   Search: "N20 motor rubber wheel 34mm"
[ ] N20 motor brackets ×2                      Search: "N20 micro motor bracket mount"
[ ] Ball caster 10mm ×1                        Search: "10mm metal ball caster module"
[ ] ST-Link V2 programmer                      Search: "ST-Link V2 STM32 programmer clone"
[ ] 10kΩ resistors ×10                         Search: "10K ohm resistor 1/4W"
[ ] XT30 connector pair ×2                     Search: "XT30 male female connector"
[ ] JST-PH 2.0mm connectors ×10               Search: "JST PH 2.0 connector kit"

STRONGLY RECOMMENDED:
[ ] 2S LiPo BMS protection board               Search: "2S 7.4V BMS protection board"
[ ] 2S LiPo balance charger                    Search: "B3AC 2S 3S LiPo balance charger"
[ ] Power switch (2A)                          Search: "SPDT toggle switch 2A"
[ ] Tactile push buttons ×2                    Search: "6x6mm tactile push button"
[ ] Status LEDs ×2 + 330Ω resistors            Search: "3mm LED assortment + 330 ohm"

OPTIONAL BUT HELPFUL:
[ ] SSD1306 OLED 0.96"                         Search: "SSD1306 I2C OLED 0.96 inch"
[ ] USB Logic Analyzer                         Search: "8 channel USB logic analyzer"
[ ] HC-05 Bluetooth module                     Search: "HC-05 Bluetooth serial module"
```

---

## 🏭 PCB Fabrication (When Ready)

When you're done prototyping on breadboard and ready for a proper PCB:

| Service | Min Order | Cost | Turnaround |
|---|---|---|---|
| **JLCPCB** | 5 boards | $2–5 + $3 shipping | 5–7 days |
| **PCBWay** | 5 boards | $5–10 + $5 shipping | 5–7 days |
| **OSH Park** | 3 boards | $5/sq inch | 7–14 days |

**Recommended workflow:**
1. Design PCB in **KiCad** (free) or **EasyEDA** (free, web-based)
2. Export Gerber files
3. Upload to JLCPCB → order 5 boards (you'll want spares)
4. Optional: add SMD assembly service for $8–15 extra

---

## 🖨️ 3D Printed Parts

If you have access to a 3D printer (or use an online service like JLCPCB 3D printing):

| Part | Material | Purpose |
|---|---|---|
| Sensor brackets (45°/90°) | PLA | Mount VL53L0X at correct angles |
| Motor mounts | PLA/PETG | Secure N20 motors to chassis |
| Battery holder | PLA | Snap-fit holder for LiPo cells |
| Wheel adapter | PLA | If wheels don't fit motor shaft |
| Full chassis | PLA/PETG | Alternative to PCB-as-chassis |

> [!TIP]
> Design in **Fusion 360** (free for personal use) or **TinkerCAD** (web-based, simpler). Export as STL.

---

## 💰 Estimated Total Cost (Components Only)

| Category | Approx Cost (USD) |
|---|---|
| Your existing parts | ~$25 |
| Critical additions | ~$15 |
| Strongly recommended | ~$10 |
| Optional | ~$8 |
| PCB fabrication (5 boards) | ~$5 |
| **Total** | **~$63** |

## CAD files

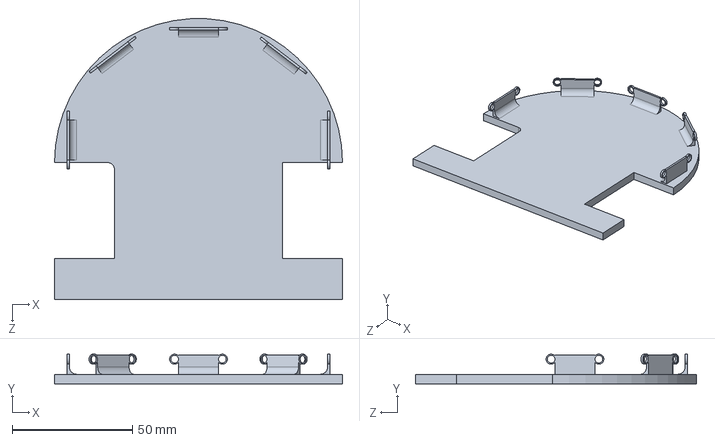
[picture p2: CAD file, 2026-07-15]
micro maze chassis.SLDPRT
120.0 x 12.4 x 116.9 mm

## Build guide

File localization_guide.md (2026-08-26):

# 📍 Micromouse Localization Module: Deep Dive & Tuning Guide

The `localization` module is the "inner ear and eyes" of your Micromouse. It answers the fundamental question: **"Where am I right now?"** 

Because wheels slip and gyro sensors drift, a single sensor is never enough. This module uses **Sensor Fusion** to combine wheel encoders (Odometry), the MPU6050 (Gyro), and the VL53L0X (Time-of-Flight Lasers) into one highly accurate `Pose` (X, Y, Theta).

Here is a full breakdown of how it works, how to tune it, and how to complete the final steps.

---

## 1. How It Works: The Three Pillars

The localization system is built on three main estimators that feed into each other.

### Pillar 1: Odometry (`odometry.cpp`)
**Goal:** Track movement purely by counting wheel rotations.
- **How it works:** It reads the change in the Left and Right encoders every millisecond.
  - Forward distance (`d_center`) = average of Left and Right distance.
  - Rotation (`d_theta`) = (Right - Left) / `WHEEL_BASE_MM`.
- **The Math:** It uses basic trigonometry to update the X and Y coordinates:
  - `X = X + d_center * cos(theta)`
  - `Y = Y + d_center * sin(theta)`
- **The Flaw:** Odometry is great for short distances, but if the wheels slip (dust on the maze floor, hard acceleration), the robot thinks it moved when it didn't. This error accumulates over time.

### Pillar 2: Heading Estimator (`heading_estimator.cpp`)
**Goal:** Fix the rotation errors from wheel slip using the Gyroscope.
- **How it works:** It uses a **Complementary Filter** to fuse the Gyro and the Encoders.
  - **Gyro:** Highly accurate in the short term, immune to wheel slip. But over 30 seconds, it slowly drifts.
  - **Encoders:** Never drift over time, but suffer from sudden wheel slip.
- **The Filter Equation:** 
  `fused_heading = (0.98 * gyro_heading) + (0.02 * encoder_heading)`
  This trusts the gyro 98% for immediate turns, but constantly pulls it 2% towards the encoders to prevent long-term drift.
- **Deadband:** If the encoders say the robot is perfectly still, it ignores tiny gyro readings to prevent noise from accumulating.

### Pillar 3: Position Estimator (`position_estimator.cpp`)
**Goal:** Fix the X/Y drift using the maze walls (ToF sensors).
- **How it works:** Even with perfect heading, the X/Y coordinates will slowly drift. But in a micromouse maze, we know the exact layout of the grid! Every cell is exactly 180mm wide.
- If the robot is driving perfectly straight North (Heading ~ 0°), and it sees a wall on its left, it knows that wall *must* be exactly at the edge of the cell.
- It calculates an `expected_y` based on the grid, subtracts the actual laser reading, and gently "tugs" the robot's internal `Y` coordinate towards reality using an Exponential Moving Average (EMA).

---

## 2. How to Tune the Localization Values

Tuning must be done in a specific order: **Physical Constants → Heading → Position**.

### Step 1: Tune Odometry (Physical Constants)
*Files involved: `config/robot_config.h`*

If odometry is wrong, everything else fails. 
1. **Drive exactly 1 meter (1000mm) forward.**
   - If the robot thinks it drove 950mm, your wheels are smaller than you thought. 
   - **Fix:** Adjust `WHEEL_DIAMETER` or `GEAR_RATIO` in `robot_config.h` until `MM_PER_COUNT` is perfect.
2. **Command the robot to spin exactly 360 degrees (10 times) in place.**
   - Measure the actual physical rotation. If it spun 370 degrees, your wheel base measurement is wrong.
   - **Fix:** Adjust `WHEEL_BASE_MM`. Increase the number if it turns too much; decrease it if it turns too little.

### Step 2: Tune the Heading Estimator (Complementary Filter)
*Files involved: `localization/heading_estimator.cpp`*

Look at this line:
```cpp
float alpha = 0.98f; 
_fused_heading_deg = alpha * (_fused_heading_deg + gyro_dtheta_deg) + (1.0f - alpha) * encoder_heading_deg;
```
- **`alpha` (0.98f):** This is the trust factor for the gyro. 
  - If your robot stutters when turning, the encoders are slipping and fighting the gyro. **Increase `alpha` to `0.99f` or `0.995f`**.
  - If your robot drives straight for a long time but slowly veers off course, the gyro is drifting. **Decrease `alpha` to `0.95f`** to trust the wheels more.

### Step 3: Tune the Deadband
*Files involved: `localization/heading_estimator.cpp`*

```cpp
if (fabs(encoder_dtheta_rad) < 0.001f && fabs(gyro_z_dps) < 1.0f)
```
- If the robot is standing completely still but the heading slowly creeps up on the OLED screen, your gyro is noisy.
- **Fix:** Increase the gyro threshold from `1.0f` to `2.0f`.

---

## 3. How to Complete the Final Step (Position Estimator)

Right now, the wall corrections in `position_estimator.cpp` are **commented out** because the code was being tested on an open floor. If you ran this on a floor without maze walls, seeing a random object (like a shoe) would completely ruin the X/Y coordinates.

Now that you are moving to the maze, you need to complete this file.

### Actions to take in `position_estimator.cpp`:

**1. Uncomment the correction block (Lines 42-54):**
Remove the `/*` and `*/` surrounding the wall correction logic.

**2. Update the Target Distance:**
Since your robot is now ~120mm wide (as updated in the `distance_manager`), the distance to the wall when perfectly centered is `30mm`. 
The old code assumed: `expected_y = cell_center + 90.0f` (edge of cell).

Let's rewrite the logic to be more robust. Replace the commented-out block with this:

```cpp
    // 4. Wall Corrections (Only if driving perfectly straight)
    // To simplify for now, we only correct when facing North (Heading ~ 0)
    // Tolerance: Must be within 3 degrees of perfect North
    if (fabs(fused_heading_deg) < 3.0f) {
        
        // Find the absolute center of the cell we are currently in
        float current_cell_center_y = cell_to_mm(mm_to_cell(_best_pose.y_mm));
        
        // If we see a left wall, it means there is a wall at +90mm from cell center.
        // The robot's left ToF sensor sits roughly 60mm from the robot center (120mm wide).
        if (distance_has_wall_left()) {
            float measured_dist = distance_get_mm(TOF_LEFT);
            // Where the robot SHOULD be based on the laser:
            // Wall is at (cell_center + 90). Robot center = Wall - measured_dist - half_width
            float laser_calculated_y = (current_cell_center_y + 90.0f) - measured_dist - 60.0f;
            
            // Gently pull our estimated Y towards the laser calculated Y (95% Odometry, 5% Laser)
            _best_pose.y_mm = (0.95f * _best_pose.y_mm) + (0.05f * laser_calculated_y);
        }
        
        // Same logic for the right wall (Right wall is at -90mm from cell center)
        if (distance_has_wall_right()) {
            float measured_dist = distance_get_mm(TOF_RIGHT);
            float laser_calculated_y = (current_cell_center_y - 90.0f) + measured_dist + 60.0f;
            
            _best_pose.y_mm = (0.95f * _best_pose.y_mm) + (0.05f * laser_calculated_y);
        }
    }
```

### 4. Tuning the Position Estimator (The `0.05f` factor)
Look at the `0.05f` (5%) weight in the equations above.
- This means every millisecond, we trust odometry 95% and the lasers 5%. 
- If the robot "snaps" violently left or right when it detects a wall, **decrease this to `0.01f` or `0.02f`** (so it corrects slower and smoother).
- If the robot crashes into the wall before the correction has time to pull it back to the center, **increase this to `0.10f`**.

### Summary of Completion Steps:
1. Ensure `WHEEL_BASE_MM` and `MM_PER_COUNT` are physically validated.
2. Replace the commented block in `position_estimator.cpp` with the math provided above, which correctly accounts for the new 120mm robot width (60mm half-width).
3. Test the robot driving down a straight hallway of maze walls. Watch the X/Y coordinates on Serial/OLED to ensure they don't wildly jump when walls appear and disappear.

---

## 5. Tuning the PID Controllers (Control Layer)

While the localization module tells the robot where it is, the **PID Controllers** take that information and calculate exactly how much PWM to apply to the motors to fix any errors. 

Tuning PID must be done from the bottom up: **Tune Speed first, then Heading**.

### Step 1: Tune Speed Control (`speed_controller.cpp`)
**Goal:** Make the wheels spin at exactly the commanded speed (mm/s) regardless of battery voltage or friction.

*Constants:*
- `SPEED_KP = 2.0f`, `SPEED_KI = 1.0f`, `SPEED_KD = 0.0f`
- `FEEDFORWARD_KV = 5.0f`

**Tuning Procedure:**
1. **Feedforward (`FEEDFORWARD_KV`):** This is the most important part for speed. Set all PID gains to `0.0f`. Command the robot to drive 500 mm/s. Look at the actual speed (via encoders). Adjust `FEEDFORWARD_KV` until the robot naturally drives at roughly 500 mm/s without any PID helping it. 
   *(Formula: `FEEDFORWARD_KV` ≈ `PWM_MAX` / `max_physical_speed_mm_s`)*
2. **Proportional (`SPEED_KP`):** Increase `SPEED_KP` slightly until the robot quickly responds to speed changes but doesn't oscillate or vibrate.
3. **Integral (`SPEED_KI`):** Add a small amount of `SPEED_KI` to eliminate steady-state error (e.g., if you command 500 but it maxes out at 490, `KI` will slowly push it up to 500 over time).
4. **Derivative (`SPEED_KD`):** Usually kept at `0.0f` for wheel speed control, as encoder speed readings are too noisy for derivative math.

### Step 2: Tune Heading Control (`heading_controller.cpp`)
**Goal:** Keep the robot driving perfectly straight or turn exactly to a target heading.

*Constants:*
- `HEADING_KP = 5.0f`, `HEADING_KI = 0.0f`, `HEADING_KD = 0.1f`

**Tuning Procedure:**
1. **Proportional (`HEADING_KP`):** Set `KI` and `KD` to `0.0f`. Command the robot to drive straight down a hallway. If it drifts off course, increase `HEADING_KP`. If the robot wiggles left and right violently (oscillating) as it drives, `KP` is too high.
2. **Derivative (`HEADING_KD`):** Add `KD` to dampen the oscillation. If `KP` makes it wiggle, `KD` acts like a shock absorber to smooth out the steering. Too much `KD` will make the steering sluggish and cause high-frequency buzzing/vibrating in the motors.
3. **Integral (`HEADING_KI`):** Usually kept at `0.0f` for heading in a micromouse. Only add a tiny amount if the robot consistently drives slightly off-center (e.g., it always maintains 2 degrees to the left of your target).

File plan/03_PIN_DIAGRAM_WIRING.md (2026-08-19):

# 03 — Pin Diagram & Wiring Guide
## STM32F401CCU6 (BlackPill) — Complete Connection Map

---

## Pin Assignment Table (STM32F401CCU6)

> [!NOTE]
> **Updated to match actual tested hardware wiring** (confirmed by working Testing Codes).
> Motor PWM uses TIM1 (PA8/PA9) at 20kHz register-level PWM.
> Encoders use TIM2/TIM3 hardware encoder mode (not software EXTI interrupts).

| STM32 Pin | Function | Connected To | Notes |
|---|---|---|---|
| **PA0** | ENC_LA | Left Motor Encoder A | TIM2 CH1 — Hardware Encoder Mode 3 |
| **PA1** | ENC_LB | Left Motor Encoder B | TIM2 CH2 — Hardware Encoder Mode 3 |
| **PA6** | ENC_RA | Right Motor Encoder A | TIM3 CH1 — Hardware Encoder Mode 3 |
| **PA7** | ENC_RB | Right Motor Encoder B | TIM3 CH2 — Hardware Encoder Mode 3 |
| **PA8** | PWM_A | TB6612FNG PWMA | TIM1 CH1 — 20kHz PWM (register-level) |
| **PA9** | PWM_B | TB6612FNG PWMB | TIM1 CH2 — 20kHz PWM (register-level) |
| **PB12** | AIN1 | TB6612FNG AIN1 | Digital output — Motor A direction |
| **PB13** | AIN2 | TB6612FNG AIN2 | Digital output — Motor A direction |
| **PB15** | BIN1 | TB6612FNG BIN1 | Digital output — Motor B direction |
| **PA10** | BIN2 | TB6612FNG BIN2 | Digital output — Motor B direction |
| **PB14** | STBY | TB6612FNG STBY | HIGH = enabled |
| **PB8** | SCL | I2C1 Clock | MPU6050 + All VL53L0X (400kHz) |
| **PB9** | SDA | I2C1 Data | MPU6050 + All VL53L0X (400kHz) |
| **PA4** | XSHUT_1 | VL53L0X #1 XSHUT (Front) | Active LOW shutdown |
| **PA15** | XSHUT_2 | VL53L0X #2 XSHUT (L-45°) | Active LOW shutdown |
| **PB3** | XSHUT_3 | VL53L0X #3 XSHUT (R-45°) | Active LOW shutdown |
| **PB1** | XSHUT_4 | VL53L0X #4 XSHUT (L-90°) | Active LOW shutdown |
| **PC14** | XSHUT_5 | VL53L0X #5 XSHUT (R-90°) | Active LOW shutdown |
| **PB0** | VBAT_ADC | Battery voltage divider | ADC input — for low-voltage cutoff |
| **PB5** | BTN_START | Push Button 1 | INPUT_PULLUP |
| **PB4** | BTN_RESET | Push Button 2 | INPUT_PULLUP (optional) |
| **PA5** | STATUS_LED | External LED + 330Ω | Active HIGH |
| **PC13** | DEBUG_LED | Onboard LED | Active LOW |
| **PA11/PA12** | USB D-/D+ | USB (if using serial debug) | |

> [!NOTE]
> **Pin utilization:** 22 pins used / ~20 pins free on STM32F401CCU6. Plenty of room for expansion (OLED, Bluetooth, extra sensors).

---

## Wiring Diagrams

### Power Wiring
```mermaid
flowchart TD
    BATT["2× 3.7V LiPo (7.4V)"] --> SW[Power Switch]
    SW --> VMBUS["7.4V BUS"]
    VMBUS --> VM[TB6612FNG VM Pin]
    VMBUS --> BUCK[MP1584 Buck Converter]
    BUCK -- 5V Output --> V5BUS["5V BUS"]
    V5BUS --> STM[STM32 5V/VIN Pin]
    V5BUS --> LDO[AMS1117-3.3 LDO]
    LDO -- 3.3V Output --> V3BUS["3.3V BUS"]
    
    V3BUS --> MPU[MPU6050 VCC]
    V3BUS --> SENSORS["VL53L0X #1..5 VDD"]
    V3BUS --> VCC[TB6612FNG VCC]
    
    GND["Common Ground Plane"] -.-> BATT
    GND -.-> BUCK
    GND -.-> LDO
    GND -.-> STM
    GND -.-> VM
    GND -.-> MPU
    
    style VMBUS fill:#f96,stroke:#333,stroke-width:2px
    style V5BUS fill:#ff9,stroke:#333,stroke-width:2px
    style V3BUS fill:#9f9,stroke:#333,stroke-width:2px
    style GND fill:#333,color:#fff,stroke:#333,stroke-width:2px
```

> [!CAUTION]
> All grounds must be connected together: Battery GND, STM32 GND, TB6612FNG GND, Sensor GND — one shared ground plane.

---

### I2C Bus Wiring (Shared)
```mermaid
flowchart LR
    SCL[STM32 PB8 - SCL] --> PULL1[4.7kΩ Pull-up]
    SDA[STM32 PB9 - SDA] --> PULL2[4.7kΩ Pull-up]
    PULL1 --> V3[3.3V]
    PULL2 --> V3
    
    SCL --> MPU[MPU6050 SCL/SDA]
    SDA --> MPU
    
    SCL --> VL1[VL53L0X #1]
    SDA --> VL1
    
    SCL --> VL2[VL53L0X #2]
    SDA --> VL2
    
    SCL --> VL3[VL53L0X #3]
    SDA --> VL3
    
    SCL --> VL4[VL53L0X #4]
    SDA --> VL4
    
    SCL --> VL5[VL53L0X #5]
    SDA --> VL5
```

> Note: Only 2 pull-up resistors needed per I2C bus (one on SCL, one on SDA). Don't add per-device.

---

### VL53L0X XSHUT Wiring (5-sensor config)
```
STM32 PA4  ──→ VL53L0X #1 XSHUT   (Front Center)
STM32 PA15 ──→ VL53L0X #2 XSHUT   (L-45°)
STM32 PB3  ──→ VL53L0X #3 XSHUT   (R-45°)
STM32 PB1  ──→ VL53L0X #4 XSHUT   (L-90°)
STM32 PC14 ──→ VL53L0X #5 XSHUT   (R-90°)

Each XSHUT also has 10kΩ pull-up to 3.3V
(keeps sensor active even if STM32 pin is floating during boot)
```

---

### TB6612FNG Wiring
```
STM32                   TB6612FNG           Motors
──────                  ─────────           ──────
PA8  (PWM_A)  ───────→  PWMA  (TIM1 CH1, 20kHz)
PB12 (AIN1)   ───────→  AIN1                      ┌─ AO1 ──→ Left Motor (+)
PB13 (AIN2)   ───────→  AIN2                      └─ AO2 ──→ Left Motor (-)
PA9  (PWM_B)  ───────→  PWMB  (TIM1 CH2, 20kHz)
PB15 (BIN1)   ───────→  BIN1                      ┌─ BO1 ──→ Right Motor (+)
PA10 (BIN2)   ───────→  BIN2                      └─ BO2 ──→ Right Motor (-)
PB14          ───────→  STBY (HIGH = active)
3.3V          ───────→  VCC  (logic power)
7.4V          ───────→  VM   (motor power)
GND           ───────→  GND
```

---

### Encoder Wiring (per motor)

> [!NOTE]
> Encoders use **hardware encoder mode** (TIM2/TIM3 in Encoder Mode 3), NOT software interrupts (EXTI).
> This gives 4× resolution (both edges of both channels) with zero CPU overhead.

```
N20 Motor Encoder       STM32              Timer
─────────────────       ─────              ─────
Left Encoder A   ─────→ PA0                TIM2 CH1 (32-bit counter)
Left Encoder B   ─────→ PA1                TIM2 CH2
Right Encoder A  ─────→ PA6                TIM3 CH1 (16-bit counter)
Right Encoder B  ─────→ PA7                TIM3 CH2
VCC (3.3V or 5V) ─────→ 3.3V
GND              ─────→ GND
```

> Some N20 encoders operate on 5V — check your datasheet. If 5V output signals, add voltage divider (10kΩ + 20kΩ) before STM32 pins to protect 3.3V GPIO.

---

### MPU6050 Wiring
```
MPU6050     STM32
───────     ─────
VCC   ────→ 3.3V
GND   ────→ GND
SCL   ────→ PB8
SDA   ────→ PB9
AD0   ────→ GND  (sets I2C address to 0x68)
```

---

## Sensor Placement Angles

### 5-Sensor Config:
```
    [L-90°] [L-45°] [FRONT] [R-45°] [R-90°]
      ←─────────── robot ──────────→

L-90°: Points directly left (wall-following)
R-90°: Points directly right (wall-following)
L-45°: Detects left-front corner/opening
R-45°: Detects right-front corner/opening
FRONT: Detects wall directly ahead
```

---

> [!WARNING]
> **Wiring Checklist**

Before powering on:
- [ ] All GNDs connected to common ground
- [ ] 7.4V not connected to STM32 or sensors directly
- [ ] 5V Buck converter output verified with multimeter before connecting
- [ ] 3.3V LDO output verified before connecting sensors
- [ ] I2C pull-ups (4.7kΩ) on SCL and SDA
- [ ] STBY pin of TB6612FNG HIGH (tied to 3.3V or STM32 pin)
- [ ] Motor polarity correct (wrong polarity just reverses direction, not harmful)
- [ ] Encoder power matches encoder spec (3.3V or 5V?)
- [ ] XSHUT lines have 10kΩ pull-ups to 3.3V
- [ ] No loose connections

---

## Color Code Convention (Recommended)

| Color | Use |
|---|-----|
| Red | 3.3V |
| Orange | 5V |
| Black | GND |
| Blue | I2C SDA |
| Yellow | I2C SCL |
| Green | PWM signals |
| White | Encoder signals |
| Purple | Motor output wires |
| Gray | XSHUT signals |

---

## Timer & Peripheral Conflict Map (STM32F401)

> [!NOTE]
> All timer assignments verified against working testing code. No conflicts.

| Timer | Channels Used | Pins | Purpose | Conflict? |
|---|---|---|---|---|
| **TIM1** | CH1, CH2 | PA8, PA9 | Motor PWM (20kHz, register-level) | ❌ No |
| **TIM2** | CH1, CH2 | PA0, PA1 | Left encoder (Hardware Encoder Mode 3, 32-bit) | ❌ No |
| **TIM3** | CH1, CH2 | PA6, PA7 | Right encoder (Hardware Encoder Mode 3, 16-bit) | ❌ No |
| **I2C1** | SCL, SDA | PB8, PB9 | Sensors + IMU (400kHz Fast I2C) | ❌ No |
| **ADC1** | CH8 | PB0 | Battery voltage reading | ❌ No |
| **USB** | D-, D+ | PA11, PA12 | Serial debug | ❌ No |

**All timers are independent — no conflicts in this configuration.** ✅

> [!TIP]
> Using hardware encoder mode (TIM2/TIM3) instead of software EXTI interrupts is a major upgrade:
> - **Zero CPU overhead** — counting happens in hardware
> - **4× resolution** — counts both edges of both channels (Encoder Mode 3)
> - **No missed pulses** at high RPM — hardware never misses edges
> - TIM2 is 32-bit (no overflow for long distances), TIM3 is 16-bit (handle with delta accumulation)

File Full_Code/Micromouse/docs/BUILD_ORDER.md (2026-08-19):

# Build and Implementation Order

This document outlines the recommended order for implementing the bodies of the generated `.c` and `.cpp` files.

## Phase 1: Hardware Bring-Up
1. `config/pin_config.h` & `config/robot_config.h` (Verify pins)
2. `hardware/led.cpp`, `hardware/button.cpp`
3. `hardware/motor.cpp` & `hardware/pwm.cpp` (Test spinning motors)
4. `hardware/encoder.cpp` (Test reading ticks)
5. `tests/test_motors.cpp` & `tests/test_encoders.cpp`

## Phase 2: Sensors & I2C
1. `sensors/mpu6050.cpp` (Test gyro reading)
2. `sensors/vl53l0x.cpp` (Test distance reading)
3. `display/oled_driver.cpp` (Get data onto the screen)

## Phase 3: Control Loop & Localization
1. `hardware/timer.cpp` (Get the 1kHz interrupt running)
2. `localization/odometry.cpp` (Track x, y, theta)
3. `sensors/sensor_fusion.cpp` (Combine gyro and encoders)
4. `control/pid.cpp` & `control/speed_controller.cpp` (Velocity control)
5. `control/heading_controller.cpp` (Drive straight)

## Phase 4: Motion & Maze Execution
1. `motion/motion_profile.cpp` & `control/trajectory_controller.cpp` (Smooth accel/decel)
2. `control/cell_controller.cpp` & `control/turn_controller.cpp` (Move 1 cell, turn 90)
3. `robot/command_executor.cpp`
4. Combine with the `maze/` logic for the search run.

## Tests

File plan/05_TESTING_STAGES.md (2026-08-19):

# 05 — Testing Stages with Code
## Test Each System Independently Before Integration

---

> [!WARNING]
> **Testing Order — NEVER skip steps**
```mermaid
flowchart TD
    A[Stage 1: Power & Voltage] --> B[Stage 2: STM32 Blink]
    B --> C[Stage 3: Motor Driver]
    C --> D[Stage 4: Encoders]
    D --> I2C[Stage 4.5: I2C Bus Scan]
    I2C --> E[Stage 5: MPU6050 IMU]
    E --> F[Stage 6: VL53L0X Sensors]
    F --> BATT[Stage 6.5: Battery Monitor]
    BATT --> G[Stage 7: PID Control]
    G --> H[Stage 8: Straight Line]
    H --> I[Stage 9: 90° Turn]
    I --> J((Stage 10: Full Integration))
    
    classDef critical fill:#f9f,stroke:#333,stroke-width:2px;
    class J critical;
```

---

## Stage 1 — Power & Voltage Check

**Before connecting anything:**
1. Connect battery through switch to buck converter input
2. Measure buck converter output → must be **5.0V ± 0.1V**
3. Connect 5V to LDO input, measure output → must be **3.3V ± 0.05V**
4. Only then connect STM32

No code needed — just a multimeter.

**✅ PASS:** 5V reads 4.9–5.1V, 3.3V reads 3.25–3.35V | **❌ FAIL:** Voltage out of range or fluctuating

---

## Stage 2 — STM32 Blink Test

**Purpose:** Confirm STM32 is alive and Arduino IDE can upload.

```cpp
// STAGE 2: Basic blink test
// Board: Generic STM32F4xx (STM32F401CCU6 BlackPill)
// Upload via: STLink

void setup() {
  pinMode(PC13, OUTPUT);  // Built-in LED on STM32F401CCU6
  Serial.begin(115200);
  Serial.println("STM32 Alive!");
}

void loop() {
  digitalWrite(PC13, LOW);   // LED ON (active low on STM32F401CCU6)
  delay(500);
  digitalWrite(PC13, HIGH);  // LED OFF
  delay(500);
}
```

**Expected:** LED blinks every 0.5s, serial prints "STM32 Alive!"

**✅ PASS:** LED blinks, serial output visible | **❌ FAIL:** No blink or no serial output

---

## Stage 3 — Motor Driver Test (No Encoders)

**Purpose:** Confirm TB6612FNG wiring and motor direction.

```cpp
// STAGE 3: Motor driver test
// Tests: Forward, Reverse, Brake, both motors independently
// Pin mapping matches actual tested hardware (TIM1 PWM at 20kHz)

#define PWMA  PA8     // TIM1 CH1
#define AIN1  PB12
#define AIN2  PB13

#define PWMB  PA9     // TIM1 CH2
#define BIN1  PB15
#define BIN2  PA10

#define STBY  PB14

void setMotorA(int speed) {
  // speed: -255 to +255
  if (speed > 0) {
    digitalWrite(AIN1, HIGH);
    digitalWrite(AIN2, LOW);
    analogWrite(PWMA, speed);
  } else if (speed < 0) {
    digitalWrite(AIN1, LOW);
    digitalWrite(AIN2, HIGH);
    analogWrite(PWMA, -speed);
  } else {
    digitalWrite(AIN1, HIGH);
    digitalWrite(AIN2, HIGH);  // Brake
    analogWrite(PWMA, 0);
  }
}

void setMotorB(int speed) {
  if (speed > 0) {
    digitalWrite(BIN1, HIGH);
    digitalWrite(BIN2, LOW);
    analogWrite(PWMB, speed);
  } else if (speed < 0) {
    digitalWrite(BIN1, LOW);
    digitalWrite(BIN2, HIGH);
    analogWrite(PWMB, -speed);
  } else {
    digitalWrite(BIN1, HIGH);
    digitalWrite(BIN2, HIGH);
    analogWrite(PWMB, 0);
  }
}

void setup() {
  Serial.begin(115200);
  pinMode(AIN1, OUTPUT);
  pinMode(AIN2, OUTPUT);
  pinMode(BIN1, OUTPUT);
  pinMode(BIN2, OUTPUT);
  pinMode(STBY, OUTPUT);
  pinMode(PWMA, OUTPUT);
  pinMode(PWMB, OUTPUT);
  digitalWrite(STBY, HIGH);  // Enable driver
  Serial.println("Motor Test Start");
}

void loop() {
  Serial.println("Both Forward");
  setMotorA(150);
  setMotorB(150);
  delay(2000);

  Serial.println("Both Stop");
  setMotorA(0);
  setMotorB(0);
  delay(1000);

  Serial.println("Both Reverse");
  setMotorA(-150);
  setMotorB(-150);
  delay(2000);

  Serial.println("Brake");
  setMotorA(0);
  setMotorB(0);
  delay(2000);
}
```

**Expected:** Motors spin forward, stop, reverse in sequence.

**✅ PASS:** Both motors respond to commands, direction matches code | **❌ FAIL:** Motor doesn't spin, wrong direction, or stutters

**If motor runs backward when it should go forward:** Swap AO1/AO2 wires (or change `AIN1/AIN2` logic in code).

---

## Stage 4 — Encoder Test

**Purpose:** Confirm quadrature encoder reading and direction detection.

> [!NOTE]
> This project uses **hardware encoder mode** (TIM2/TIM3 Encoder Mode 3) instead of software EXTI interrupts.
> This is superior: zero CPU overhead, 4× resolution, no missed pulses at high RPM.
> Left encoder uses TIM2 (PA0/PA1, 32-bit). Right encoder uses TIM3 (PA6/PA7, 16-bit).

```cpp
// STAGE 4: Encoder reading test
// Uses TIM2/TIM3 hardware encoder mode (register-level setup)

#include <Arduino.h>

void setupLeftEncoder() {
  RCC->AHB1ENR |= RCC_AHB1ENR_GPIOAEN;
  RCC->APB1ENR |= RCC_APB1ENR_TIM2EN;

  // PA0 PA1 Alternate Function (TIM2 CH1 and CH2)
  GPIOA->MODER &= ~(3 << (0 * 2));
  GPIOA->MODER &= ~(3 << (1 * 2));
  GPIOA->MODER |= (2 << (0 * 2));
  GPIOA->MODER |= (2 << (1 * 2));

  // AF1 for TIM2
  GPIOA->AFR[0] &= ~(0xF << 0);
  GPIOA->AFR[0] &= ~(0xF << 4);
  GPIOA->AFR[0] |= (1 << 0);
  GPIOA->AFR[0] |= (1 << 4);

  // Reset and configure timer
  TIM2->CR1 = 0; TIM2->CR2 = 0; TIM2->SMCR = 0;
  TIM2->CCMR1 = 0; TIM2->CCER = 0;
  TIM2->PSC = 0;
  TIM2->ARR = 0xFFFFFFFF; // TIM2 is 32-bit

  // Encoder Mode 3 (count on both edges of both channels)
  TIM2->SMCR |= TIM_SMCR_SMS_0 | TIM_SMCR_SMS_1;
  TIM2->CCMR1 |= TIM_CCMR1_CC1S_0 | TIM_CCMR1_CC2S_0;
  TIM2->CCMR1 |= (3 << 4) | (3 << 12); // Input filter

  TIM2->CNT = 0;
  TIM2->CR1 |= TIM_CR1_CEN;
}

void setupRightEncoder() {
  RCC->AHB1ENR |= RCC_AHB1ENR_GPIOAEN;
  RCC->APB1ENR |= RCC_APB1ENR_TIM3EN;

  // PA6 PA7 Alternate Function (TIM3 CH1 and CH2)
  GPIOA->MODER &= ~(3 << (6 * 2));
  GPIOA->MODER &= ~(3 << (7 * 2));
  GPIOA->MODER |= (2 << (6 * 2));
  GPIOA->MODER |= (2 << (7 * 2));

  // AF2 for TIM3
  GPIOA->AFR[0] &= ~(0xF << (6 * 4));
  GPIOA->AFR[0] &= ~(0xF << (7 * 4));
  GPIOA->AFR[0] |= (2 << (6 * 4));
  GPIOA->AFR[0] |= (2 << (7 * 4));

  // Reset and configure timer
  TIM3->CR1 = 0; TIM3->CR2 = 0; TIM3->SMCR = 0;
  TIM3->CCMR1 = 0; TIM3->CCER = 0;
  TIM3->PSC = 0;
  TIM3->ARR = 0xFFFF; // TIM3 is 16-bit

  // Encoder Mode 3
  TIM3->SMCR |= TIM_SMCR_SMS_0 | TIM_SMCR_SMS_1;
  TIM3->CCMR1 |= TIM_CCMR1_CC1S_0 | TIM_CCMR1_CC2S_0;
  TIM3->CCMR1 |= (3 << 4) | (3 << 12); // Input filter

  TIM3->CNT = 0;
  TIM3->CR1 |= TIM_CR1_CEN;
}

int32_t getLeftCount() {
  return (int32_t)TIM2->CNT;
}

int32_t getRightCount() {
  return (int32_t)(int16_t)TIM3->CNT; // 16-bit sign extension
}

void setup() {
  Serial.begin(115200);
  setupLeftEncoder();
  setupRightEncoder();
  Serial.println("Encoder Test — spin wheels by hand");
}

void loop() {
  Serial.print("Left: ");
  Serial.print(getLeftCount());
  Serial.print("  Right: ");
  Serial.println(getRightCount());
  delay(100);
}
```

**Expected:**
- Spinning left wheel forward → count increases
- Spinning left wheel backward → count decreases
- Same for right
- If direction is wrong: swap encoder A/B wires physically

**Pulses per revolution:**
- Manually spin wheel exactly once → note encoder count
- This is your **CPR (counts per revolution)**
- With hardware encoder mode 3, you get 4× the base PPR
- Record this value for odometry calculations

**✅ PASS:** Forward spin increases count, backward decreases. Consistent CPR. | **❌ FAIL:** Count stays at 0, or inconsistent

---

## Stage 4.5 — I2C Bus Scan

**Purpose:** Verify all I2C devices are detected before testing them individually.

```cpp
// STAGE 4.5: I2C bus scanner
// Detects all devices on the I2C bus

#include <Wire.h>

void setup() {
  Serial.begin(115200);
  Wire.begin(PB9, PB8);  // SDA, SCL for STM32
  Wire.setClock(400000);
  Serial.println("I2C Bus Scanner");
  Serial.println("Scanning...");
}

void loop() {
  int devices = 0;
  
  for (byte addr = 8; addr < 120; addr++) {
    Wire.beginTransmission(addr);
    byte error = Wire.endTransmission();
    
    if (error == 0) {
      Serial.print("Device found at 0x");
      if (addr < 16) Serial.print("0");
      Serial.print(addr, HEX);
      
      // Identify known devices
      if (addr == 0x68) Serial.print(" ← MPU6050");
      if (addr == 0x69) Serial.print(" ← MPU6050 (AD0=HIGH)");
      if (addr == 0x29) Serial.print(" ← VL53L0X (default)");
      if (addr >= 0x30 && addr <= 0x35) {
        Serial.print(" ← VL53L0X #");
        Serial.print(addr - 0x2F);
      }
      if (addr == 0x3C || addr == 0x3D) Serial.print(" ← SSD1306 OLED");
      
      Serial.println();
      devices++;
    }
  }
  
  Serial.print("\nTotal devices found: ");
  Serial.println(devices);
  Serial.println("---");
  delay(5000);
}
```

**Expected:**
- MPU6050 at 0x68 (with AD0=GND) or 0x69 (AD0=HIGH)
- VL53L0X at 0x29 (before address assignment) or assigned addresses

**✅ PASS:** All expected devices detected | **❌ FAIL:** Missing devices — check wiring, pull-ups, and power

---

## Stage 5 — MPU6050 Test

**Install library first:** Tools → Manage Libraries → search "MPU6050" by Electronic Cats or Jeff Rowberg

```cpp
// STAGE 5: MPU6050 gyroscope test
#include <Wire.h>
#include <MPU6050.h>

MPU6050 mpu;

float yaw = 0;
unsigned long lastTime = 0;

void setup() {
  Serial.begin(115200);
  Wire.begin(PB9, PB8);  // SDA, SCL for STM32
  Wire.setClock(400000); // 400kHz Fast I2C
  
  mpu.initialize();
  if (!mpu.testConnection()) {
    Serial.println("MPU6050 NOT FOUND! Check wiring.");
    while (1);
  }
  mpu.setFullScaleGyroRange(MPU6050_GYRO_FS_500);
  mpu.setFullScaleAccelRange(MPU6050_ACCEL_FS_4);
  
  Serial.println("MPU6050 OK. Calibrating — keep still for 3 seconds...");
  delay(3000);
  Serial.println("Done. Rotate robot and watch yaw.");
  lastTime = millis();
}

void loop() {
  int16_t ax, ay, az, gx, gy, gz;
  mpu.getMotion6(&ax, &ay, &az, &gx, &gy, &gz);
  
  float gyroZ = gz / 65.5;  // Convert to degrees/sec (65.5 LSB per deg/s at 500dps range)
  // Note: at 250dps range, divide by 131.0 instead
  
  unsigned long now = millis();
  float dt = (now - lastTime) / 1000.0;
  lastTime = now;
  
  yaw += gyroZ * dt;
  
  Serial.print("Yaw: ");
  Serial.print(yaw, 2);
  Serial.println("°");
  
  delay(20);  // 50Hz update
}
```

**Expected:**
- Robot still: yaw stays near 0 (±0.5° drift per minute acceptable)
- Robot rotated 90° right: yaw shows ~90
- Robot rotated 90° left: yaw shows ~-90

**✅ PASS:** Yaw drift < 1°/min when still, and reads ±5° of expected when rotated | **❌ FAIL:** Rapid drift or no reading

**If MPU6050 not found:** Check I2C address — AD0 pin LOW = 0x68, AD0 HIGH = 0x69. Check pull-ups.

---

## Stage 6 — VL53L0X Sensor Test

1. Open Arduino IDE -> Sketch -> Include Library -> Manage Libraries
2. Search for **Adafruit VL53L0X** and install it.

### Basic Single Sensor Test

```cpp
#include <Wire.h>
#include "Adafruit_VL53L0X.h"

Adafruit_VL53L0X lox = Adafruit_VL53L0X();

void setup() {
  Serial.begin(115200);
  Wire.begin();
  
  if (!lox.begin()) {
    Serial.println(F("Failed to boot VL53L0X"));
    while(1);
  }
}

void loop() {
  VL53L0X_RangingMeasurementData_t measure;
  lox.rangingTest(&measure, false);
  
  if (measure.RangeStatus != 4) {
    Serial.print("Distance: "); Serial.print(measure.RangeMilliMeter); Serial.println(" mm");
  } else {
    Serial.println("Out of range");
  }
  delay(100);
}
```

### 5-Sensor Initialization (XSHUT Routing)

```cpp
#include <Wire.h>
#include "Adafruit_VL53L0X.h"

// Define XSHUT pins
#define XSHUT_1 PA4  // Front
#define XSHUT_2 PA15 // Front-Left
#define XSHUT_3 PB3  // Front-Right
#define XSHUT_4 PB1  // Left
#define XSHUT_5 PC14 // Right

// Object for each sensor
Adafruit_VL53L0X lox1 = Adafruit_VL53L0X();
Adafruit_VL53L0X lox2 = Adafruit_VL53L0X();
Adafruit_VL53L0X lox3 = Adafruit_VL53L0X();
Adafruit_VL53L0X lox4 = Adafruit_VL53L0X();
Adafruit_VL53L0X lox5 = Adafruit_VL53L0X();

void assignSensorAddresses() {
  // Shut all down first
  pinMode(XSHUT_1, OUTPUT); pinMode(XSHUT_2, OUTPUT); pinMode(XSHUT_3, OUTPUT); pinMode(XSHUT_4, OUTPUT); pinMode(XSHUT_5, OUTPUT);
  digitalWrite(XSHUT_1, LOW); digitalWrite(XSHUT_2, LOW); digitalWrite(XSHUT_3, LOW); digitalWrite(XSHUT_4, LOW); digitalWrite(XSHUT_5, LOW);
  delay(10);
  
  // Enable sensor 1 (Front)
  digitalWrite(XSHUT_1, HIGH); delay(10);
  sensor1.init(); sensor1.setAddress(ADDR_1);
  Serial.println("Sensor 1 (Front) initialized at 0x30");
  
  // Enable sensor 2 (L-45)
  digitalWrite(XSHUT_2, HIGH); delay(10);
  sensor2.init(); sensor2.setAddress(ADDR_2);
  Serial.println("Sensor 2 (L-45) initialized at 0x31");
  
  // Enable sensor 3 (R-45)
  digitalWrite(XSHUT_3, HIGH); delay(10);
  sensor3.init(); sensor3.setAddress(ADDR_3);
  Serial.println("Sensor 3 (R-45) initialized at 0x32");

  // Enable sensor 4 (L-90)
  digitalWrite(XSHUT_4, HIGH); delay(10);
  sensor4.init(); sensor4.setAddress(ADDR_4);
  Serial.println("Sensor 4 (L-90) initialized at 0x33");

  // Enable sensor 5 (R-90)
  digitalWrite(XSHUT_5, HIGH); delay(10);
  sensor5.init(); sensor5.setAddress(ADDR_5);
  Serial.println("Sensor 5 (R-90) initialized at 0x34");
}

void setup() {
  Serial.begin(115200);
  Wire.begin(PB9, PB8);
  Wire.setClock(400000);
  
  assignSensorAddresses();
  
  // Set to high speed mode (shorter range but faster)
  sensor1.setMeasurementTimingBudget(20000);  // 20ms per reading
  sensor2.setMeasurementTimingBudget(20000);
  sensor3.setMeasurementTimingBudget(20000);
  sensor4.setMeasurementTimingBudget(20000);
  sensor5.setMeasurementTimingBudget(20000);
  
  sensor1.startContinuous();
  sensor2.startContinuous();
  sensor3.startContinuous();
  sensor4.startContinuous();
  sensor5.startContinuous();
  
  Serial.println("Sensors ready. Move objects in front of them.");
}

void loop() {
  int d1 = sensor1.readRangeContinuousMillimeters();
  int d2 = sensor2.readRangeContinuousMillimeters();
  int d3 = sensor3.readRangeContinuousMillimeters();
  int d4 = sensor4.readRangeContinuousMillimeters();
  int d5 = sensor5.readRangeContinuousMillimeters();
  
  Serial.print("L-90: "); Serial.print(d4); Serial.print("mm ");
  Serial.print("L-45: "); Serial.print(d2); Serial.print("mm ");
  Serial.print("Front: "); Serial.print(d1); Serial.print("mm ");
  Serial.print("R-45: "); Serial.print(d3); Serial.print("mm ");
  Serial.print("R-90: "); Serial.print(d5); Serial.println("mm");
  
  // 65535 = out of range / timeout
  delay(50);
}
```

**Expected:**
- Open air: ~1200mm or 65535 (timeout)
- Hand 200mm away: ~200mm reading
- Each sensor responds independently

**✅ PASS:** All 3 sensors respond, readings match real distance ±10mm | **❌ FAIL:** 65535 constantly, or sensor not initializing

---

## Stage 6.5 — Battery Voltage Monitor Test

**Purpose:** Read battery voltage via ADC for low-voltage protection.

**Wiring:** Create a voltage divider: Battery+ → 20kΩ → PB0 → 10kΩ → GND
(This divides 8.4V max down to 2.8V — safe for 3.3V ADC)

```cpp
// STAGE 6.5: Battery voltage monitor

#define VBAT_PIN PB0
#define DIVIDER_RATIO 3.0    // (20k + 10k) / 10k = 3.0
#define ADC_REF 3.3
#define ADC_MAX 4095.0       // 12-bit ADC

void setup() {
  Serial.begin(115200);
  pinMode(VBAT_PIN, INPUT_ANALOG);
  Serial.println("Battery Monitor Test");
}

void loop() {
  // Average 10 readings for stability
  long sum = 0;
  for (int i = 0; i < 10; i++) {
    sum += analogRead(VBAT_PIN);
    delay(2);
  }
  float adcAvg = sum / 10.0;
  
  float voltage = (adcAvg / ADC_MAX) * ADC_REF * DIVIDER_RATIO;
  float cellVoltage = voltage / 2.0;  // 2S pack
  
  Serial.print("Battery: ");
  Serial.print(voltage, 2);
  Serial.print("V  Cell: ");
  Serial.print(cellVoltage, 2);
  Serial.print("V  ");
  
  if (cellVoltage > 3.7) Serial.println("[GOOD]");
  else if (cellVoltage > 3.5) Serial.println("[OK]");
  else if (cellVoltage > 3.2) Serial.println("[LOW - charge soon]");
  else Serial.println("[CRITICAL - STOP IMMEDIATELY!]");
  
  delay(1000);
}
```

**Expected:**
- Fully charged: ~8.2–8.4V (4.1–4.2V/cell)
- Normal use: 7.0–7.8V (3.5–3.9V/cell)

**✅ PASS:** Voltage reading matches multimeter ±0.1V | **❌ FAIL:** Reading is 0 or wildly inaccurate

---

## Stage 7 — PID Motor Speed Control

**Purpose:** Make motors run at target RPM accurately.

```cpp
// STAGE 7: PID speed control test
// Uses hardware encoder mode (TIM2/TIM3) and motor driver from Stages 3 & 4
// Pin mapping matches actual tested hardware

// Include motor driver setup from Stage 3 (PA8/PA9, PB12/PB13/PB15/PA10, PB14)
// Include encoder setup from Stage 4 (TIM2: PA0/PA1, TIM3: PA6/PA7)
// Then add:

#define COUNTS_PER_REV 600.0    // Counts per revolution (measure in stage 4!)
#define MM_PER_COUNT   0.05869f // Calibrated mm per encoder count
#define SAMPLE_TIME    0.01f    // 10ms PID loop

// PID gains — tune these (start low!)
float Kp = 1.8, Ki = 0.8, Kd = 0.02;

float targetLeftSpeed = 300.0f;   // mm/s
float targetRightSpeed = 300.0f;  // mm/s
float leftSpeed = 0, rightSpeed = 0;
float leftPWM = 0, rightPWM = 0;

int32_t lastLeftCount = 0;
int16_t lastRightCount = 0;
unsigned long lastPID = 0;

struct PIDController {
  float kp, ki, kd;
  float error, previousError, integral, derivative;
};

PIDController leftPID, rightPID;

void setupPID() {
  leftPID.kp = Kp;  leftPID.ki = Ki;  leftPID.kd = Kd;
  leftPID.error = 0; leftPID.previousError = 0;
  leftPID.integral = 0; leftPID.derivative = 0;
  rightPID = leftPID;
}

float calculatePID(PIDController &pid, float target, float actual) {
  pid.error = target - actual;
  pid.integral += pid.error * SAMPLE_TIME;
  pid.integral = constrain(pid.integral, -500, 500);  // Anti-windup
  pid.derivative = (pid.error - pid.previousError) / SAMPLE_TIME;
  float output = pid.kp * pid.error + pid.ki * pid.integral + pid.kd * pid.derivative;
  pid.previousError = pid.error;
  return output;
}

void updateSpeed() {
  int32_t currentLeft = TIM2->CNT;
  int32_t leftDelta = currentLeft - lastLeftCount;
  lastLeftCount = currentLeft;

  int16_t currentRight = (int16_t)TIM3->CNT;
  int16_t rightDelta = -(currentRight - lastRightCount); // Negate if needed
  lastRightCount = currentRight;

  leftSpeed = (leftDelta * MM_PER_COUNT) / SAMPLE_TIME;
  rightSpeed = (rightDelta * MM_PER_COUNT) / SAMPLE_TIME;
}

void updateMotorPID() {
  updateSpeed();
  leftPWM += calculatePID(leftPID, targetLeftSpeed, leftSpeed);
  rightPWM += calculatePID(rightPID, targetRightSpeed, rightSpeed);
  leftPWM = constrain(leftPWM, 0, 4999);
  rightPWM = constrain(rightPWM, 0, 4999);
  // Apply to TIM1 compare registers directly
  TIM1->CCR1 = (uint16_t)leftPWM;
  TIM1->CCR2 = (uint16_t)rightPWM;
}

void setup() {
  Serial.begin(115200);
  analogWriteResolution(13);  // 0-8191 range for PWM
  setupMotorDriver();  // From Stage 3
  setupLeftEncoder();  // From Stage 4
  setupRightEncoder();
  setupPID();
  delay(2000);

  // Set motors forward
  digitalWrite(AIN1, HIGH); digitalWrite(AIN2, LOW);
  digitalWrite(BIN1, HIGH); digitalWrite(BIN2, LOW);
}

void loop() {
  if (millis() - lastPID >= 10) {
    lastPID = millis();
    updateMotorPID();

    Serial.print("Target:"); Serial.print(targetLeftSpeed);
    Serial.print(",Left:"); Serial.print(leftSpeed);
    Serial.print(",Right:"); Serial.println(rightSpeed);
  }
}
```

**Expected:** Both motors run at ~150 RPM. PWM values settle after a few seconds.

**✅ PASS:** RPM stabilizes within ±10 of target in <3 seconds | **❌ FAIL:** Oscillating, maxing out, or no response

---

## Stage 8 — Straight Line Test

**Purpose:** Robot drives straight without drifting.

Combine PID speed control with encoder odometry feedback. Set both motors to same target speed.

```cpp
// After Stage 7 is working:
// Add this — corrections to keep robot straight using encoder differential

float straightCorrection(long encL, long encR) {
  float diff = encL - encR;  // If positive, left went further → need to slow left
  return diff * 0.5;          // Correction gain — tune this
}

// In main loop:
float correction = straightCorrection(encoderL, encoderR);
float targetL = TARGET_RPM - correction;
float targetR = TARGET_RPM + correction;
// Feed targetL, targetR into PID instead of fixed TARGET_RPM
```

**Expected:** Robot drives 1 meter in a straight line (<5mm lateral deviation).

**✅ PASS:** <5mm deviation over 1 meter | **❌ FAIL:** Curves or oscillates

---

## Stage 9 — 90° Turn Test

```cpp
// Turn left 90 degrees using encoder counting

void turnLeft90() {
  // Calculate encoder counts for 90° turn
  // Arc length = (PI/2) * wheelbase_radius
  // wheelbase = distance between wheel centers (measure yours, e.g. 70mm)
  float wheelbase = 70.0;   // mm
  float wheelDiam = 34.0;   // mm
  float wheelCirc = PI * wheelDiam;
  float arcLength = (PI / 2.0) * (wheelbase / 2.0);
  int targetCounts = (int)(arcLength / wheelCirc * ENCODER_CPR);
  
  long startL = encoderL;
  long startR = encoderR;
  
  // Left motor backward, right motor forward
  setMotorA(-120);  // Left backward
  setMotorB(120);   // Right forward
  
  while (true) {
    long dL = abs(encoderL - startL);
    long dR = abs(encoderR - startR);
    long avg = (dL + dR) / 2;
    if (avg >= targetCounts) break;
  }
  
  setMotorA(0);
  setMotorB(0);
}
```

**Expected:** Robot turns approximately 90°. Verify with MPU6050 yaw reading.

**✅ PASS:** Turn within ±5° of 90° | **❌ FAIL:** Under/overshooting significantly

After passing this, combine gyro feedback for more accurate turns (see `06_MAIN_LOGIC_CODE.md`).

---

## Stage 10 — Full Integration Test

**Purpose:** Verify all subsystems work together in a controlled mini-maze.

### Test Environment:
- Build a 2×2 or 3×3 mini-maze with cardboard walls (18cm cells, 5cm tall walls)
- Start robot in corner cell

### Integration Test Code:
```cpp
// STAGE 10: Full integration test
// Runs a simplified exploration in a small test maze

// Include ALL code from stages 3-9 and 06_MAIN_LOGIC_CODE.md
// Set MAZE_SIZE to 4 for a small test maze:
// #define MAZE_SIZE 4

// Override goal to cell (1,1) for small maze:
// bool isGoal(int x, int y) { return x == 1 && y == 1; }

void setup() {
  Serial.begin(115200);
  Serial.println("=== FULL INTEGRATION TEST ===");
  
  initMotors();
  initSensors();
  calibrateGyro();  // From 07_TUNING_CALIBRATION
  
  // Initialize small maze
  memset(walls, 0, sizeof(walls));
  memset(visited, 0, sizeof(visited));
  
  // Set border walls for small maze
  for (int i = 0; i < MAZE_SIZE; i++) {
    walls[0][i]           |= 8;  // West
    walls[MAZE_SIZE-1][i] |= 2;  // East
    walls[i][0]           |= 4;  // South
    walls[i][MAZE_SIZE-1] |= 1;  // North
  }
  
  floodFill();
  
  pinMode(BTN_START, INPUT_PULLUP);
  Serial.println("Press START button.");
  while (digitalRead(BTN_START) == HIGH);
  delay(1000);  // 1 second delay after button press
  
  Serial.println("Running!");
}

void loop() {
  // Print state before each step
  printMazeState();  // From 08_TROUBLESHOOTING
  
  // Check battery
  float vbat = readBatteryVoltage();
  if (vbat < 6.4) {
    setMotors(0, 0);
    Serial.println("LOW BATTERY! STOPPING.");
    while(1);
  }
  
  exploreStep();
  
  if (goalReached) {
    setMotors(0, 0);
    Serial.println("=== GOAL REACHED! TEST PASSED! ===");
    // Print final maze map
    for (int y = MAZE_SIZE-1; y >= 0; y--) {
      for (int x = 0; x < MAZE_SIZE; x++) {
        Serial.print(floodValues[x][y]);
        Serial.print("\t");
      }
      Serial.println();
    }
    while(1);  // Stop
  }
}
```

### Integration Checklist:
- [ ] Robot reads sensors without crashing when motors are running
- [ ] Wall detection matches physical walls in test maze
- [ ] Robot navigates at least 3 cells correctly
- [ ] Turns are accurate (±5°)
- [ ] Robot stops at goal cell
- [ ] Battery voltage reads correctly under motor load
- [ ] No I2C lockups during 5-minute continuous run

**✅ PASS:** Robot completes mini-maze without errors | **❌ FAIL:** See `08_TROUBLESHOOTING.md`

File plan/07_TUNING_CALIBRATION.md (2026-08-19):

# 07 — Tuning & Calibration Guide

---

## Step 1: Measure Physical Constants

### Wheel Diameter
```
1. Mark a point on wheel with paint/marker
2. Roll robot exactly 1 meter on flat surface
3. Count rotations (mark shows how many)
4. Diameter = 1000mm / (rotations × π)

Typical N20 wheel: 34–40mm
Update WHEEL_DIAMETER_MM in code.
```

### Wheelbase
```
1. Measure distance between the contact points of both wheels
2. (Center of left wheel to center of right wheel)
Typical: 60–80mm
Update WHEELBASE_MM in code.
```

### Encoder CPR (Counts Per Revolution)
```
1. Mark wheel, run Stage 4 encoder test code
2. Slowly rotate wheel exactly one full turn by hand
3. Read encoder count from Serial Monitor
4. That is your CPR
Update ENCODER_CPR in code.

Cross-check: N20 300RPM usually has 7 PPR on motor shaft.
If gear ratio is 65:1 → CPR = 7 × 65 × 4 (if quadrature) = 1820
Or with single-edge interrupt: 7 × 65 = 455
```

---

## Step 2: Calibrate Sensors

### VL53L0X Zero-Distance Calibration
```cpp
// Place a flat wall at exactly 100mm from sensor face
// Read value from sensor
// If it reads 95mm, offset = +5mm
// Add offset to all readings:
#define SENSOR_FRONT_OFFSET  5   // mm correction
#define SENSOR_LEFT_OFFSET   3
#define SENSOR_RIGHT_OFFSET  4

int correctedFront = s.front + SENSOR_FRONT_OFFSET;
```

### Wall Detection Threshold
```
1. Put robot in maze cell
2. Read sensor values with wall present: should be ~80–150mm
3. Read values without wall: should be 250–1200mm
4. Set threshold between these values, e.g. 200mm

Refine for each sensor direction (front vs side angles differ).
```

### Sensor Angle Verification
```
1. Place robot parallel to wall
2. Both side sensors should read same distance (±5mm)
3. If not: physically adjust sensor mounting angle
4. Fine-tune with software:

float leftReading = sensorLeft.read() * cos(sensorLeftAngleDeg * PI / 180.0);
```

---

## Step 3: PID Tuning (Ziegler-Nichols Method)

### Speed PID (for each motor independently):

```mermaid
flowchart LR
    Target[Target RPM] --> Error((+ / -))
    Current[Actual RPM] --> Error
    Error --> P[Kp * Error]
    Error --> I[Ki * Integral]
    Error --> D[Kd * Derivative]
    P --> Sum((+))
    I --> Sum
    D --> Sum
    Sum --> Motor[Motor PWM]
    Motor --> Plant[Motor/Wheel]
    Plant --> Encoder[Encoder]
    Encoder --> Calc[RPM Calc]
    Calc --> Current
    
    style Error fill:#f9f,stroke:#333,stroke-width:2px
    style Sum fill:#f9f,stroke:#333,stroke-width:2px
```

```
Start with: Kp=1, Ki=0, Kd=0

Step 1 — Tune Kp:
  Increase Kp until motor just starts oscillating (hunting)
  That is Ku (ultimate gain), period of oscillation is Tu

Step 2 — Set gains (Ziegler-Nichols):
  Kp = 0.6 × Ku
  Ki = 2 × Kp / Tu
  Kd = Kp × Tu / 8

Step 3 — Fine tune:
  If overshoot: reduce Kp or Kd
  If slow response: increase Kp
  If steady-state error: increase Ki
  If oscillation: reduce Ki
```

### Typical starting values for N20 300RPM with PID at 50Hz:
```
Kp_speed = 2.0–3.0
Ki_speed = 0.5–1.0
Kd_speed = 0.05–0.15
```

### Straight-line correction gain:
```
Kp_straight = start at 0.5, increase until robot barely oscillates
Typical: 1.0–3.0
```

---

## Step 4: Gyro Calibration

### Gyro Zero-Rate Offset (Bias Calibration)
```cpp
// Run this at startup while robot is still
void calibrateGyro() {
  const int samples = 500;
  long sumGz = 0;
  
  for (int i = 0; i < samples; i++) {
    int16_t ax, ay, az, gx, gy, gz;
    mpu.getMotion6(&ax, &ay, &az, &gx, &gy, &gz);
    sumGz += gz;
    delay(2);
  }
  
  gyroBiasZ = sumGz / (float)samples;
  Serial.print("Gyro Z bias: ");
  Serial.println(gyroBiasZ);
}

// Then in readGyroYaw():
float gyroZ = (gz - gyroBiasZ) / 65.5;  // Subtract bias
```

### Temperature effect:
- Gyro bias drifts with temperature
- Always calibrate after 2–3 minutes warm-up
- Recalibrate if environment temperature changes significantly

---

## Step 5: Turn Calibration

### 90° Turn Accuracy Test:
```
1. Place robot at known position
2. Command 10 consecutive 90° right turns (full 360° × 2.5)
3. Robot should end facing original direction
4. Measure actual heading vs expected

If robot ends 10° off after 10 turns:
  Error per turn = 10°/10 = 1°
  Scale correction factor: 91/90 = 1.011
  
  Apply in code:
  #define TURN_90_CORRECTION  1.011  // Scale target angle
  float targetAngle = 90.0 * TURN_90_CORRECTION;
```

### Turn Speed vs Accuracy Tradeoff:
- Faster turns = less accurate (gyro latency, wheel slip)
- Slower turns = more accurate but slower maze run
- Recommended: exploration at 80–100 PWM, speed run at 150+ PWM turns

---

## Step 6: Cell Navigation Calibration

### One-cell forward distance:
```
1. Mark start position
2. Command moveForward() once
3. Measure actual distance traveled
4. If 175mm instead of 180mm:
   CELL_SIZE_MM = 175.0  (use your measured value)
   
OR scale encoder target:
   targetCounts = targetCounts * (180.0/175.0)
```

### Centering in corridor using side sensors:
```cpp
void centerInCorridor() {
  int leftDist  = sensorLeft.read();
  int rightDist = sensorRight.read();
  
  // If both walls present, we can center
  if (leftDist < WALL_PRESENT_THRESHOLD && rightDist < WALL_PRESENT_THRESHOLD) {
    int error = leftDist - rightDist;  // Positive = too close to right
    float correction = error * 0.3;   // Gentle correction
    // Apply to motor speeds during forward movement
  }
}
```

---

## Recommended Calibration Order

1. Physical measurements (wheel diameter, wheelbase, CPR)
2. Gyro bias calibration
3. Sensor distance offsets
4. Motor speed PID (test on bench with wheels lifted)
5. Straight-line correction (test on floor)
6. Turn calibration (single turns)
7. Full cell navigation (one cell forward and back)
8. Corner detection (enter turn at right point)
9. Full maze run test

---

## Quick Diagnostic Checks

| Symptom | Likely Cause | Fix |
|---|---|-----|
| Drifts left during straight | Right motor faster | Decrease right PID setpoint or check encoder CPR |
| Turns >90° | Gyro overcounting | Reduce TURN_90_CORRECTION or check bias |
| Turns <90° | Wheel slip on turn | Slow down turn speed, check wheel grip |
| Wall not detected | Threshold too low | Increase WALL_PRESENT_THRESHOLD |
| False wall detection | Sensor noise | Add median filter, check mounting angle |
| Robot freezes mid-maze | I2C hang (VL53L0X) | Add timeout/watchdog reset to I2C reads |
| Encoders count wrong | Wrong interrupt edge | Change RISING to CHANGE, divide count by 2 |

---

## Step 7: Automated PID Self-Tuning Routine

Instead of manually tuning, this routine measures the step response and calculates PID gains:

```cpp
// Self-tuning routine — run with wheels raised off the ground!
// Measures the motor's step response to calculate optimal PID gains

void autoTunePID() {
  Serial.println("=== PID Auto-Tune ===");
  Serial.println("LIFT WHEELS OFF THE GROUND!");
  Serial.println("Starting in 3 seconds...");
  delay(3000);
  
  // Step 1: Apply a step input and measure response
  int stepPWM = 150;  // Test PWM value
  long startEnc = encoderL;
  unsigned long startTime = millis();
  
  setMotorA(stepPWM);
  
  // Measure RPM over time to find rise time and overshoot
  float maxRPM = 0;
  float steadyRPM = 0;
  unsigned long riseTime = 0;
  bool foundPeak = false;
  float prevRPM = 0;
  long prevEnc = encoderL;
  
  for (int i = 0; i < 200; i++) {  // 4 seconds at 20ms interval
    delay(20);
    long dEnc = encoderL - prevEnc;
    prevEnc = encoderL;
    float rpm = (dEnc / ENCODER_CPR) * (60.0 / 0.02);
    
    if (rpm > maxRPM) maxRPM = rpm;
    if (i > 150) steadyRPM += rpm;  // Average last 1 second
    
    if (!foundPeak && rpm > 0.95 * maxRPM && i > 5) {
      riseTime = i * 20;  // ms
      foundPeak = true;
    }
    
    Serial.print(i * 20); Serial.print("ms: ");
    Serial.print(rpm, 1); Serial.println(" RPM");
  }
  
  setMotorA(0);
  steadyRPM /= 50.0;
  
  // Step 2: Calculate suggested PID gains
  float Ku = stepPWM / (steadyRPM * 0.1);  // Approximate ultimate gain
  float Tu = riseTime * 4.0 / 1000.0;       // Approximate ultimate period
  
  float suggestedKp = 0.6 * Ku;
  float suggestedKi = 2.0 * suggestedKp / Tu;
  float suggestedKd = suggestedKp * Tu / 8.0;
  
  Serial.println("\n=== AUTO-TUNE RESULTS ===");
  Serial.print("Steady-state RPM: "); Serial.println(steadyRPM, 1);
  Serial.print("Rise time: "); Serial.print(riseTime); Serial.println(" ms");
  Serial.print("Max RPM: "); Serial.println(maxRPM, 1);
  Serial.println("\nSuggested PID gains:");
  Serial.print("  Kp = "); Serial.println(suggestedKp, 3);
  Serial.print("  Ki = "); Serial.println(suggestedKi, 3);
  Serial.print("  Kd = "); Serial.println(suggestedKd, 4);
  Serial.println("\nUse these as starting point, then fine-tune.");
}
```

---

## Step 8: Sensor Noise Characterization

Before trusting your sensors, measure their noise floor:

```cpp
// Measure VL53L0X noise — place sensor 100mm from a flat wall
// and record 100 readings to compute standard deviation

void characterizeSensorNoise(VL53L0X& sensor, const char* name) {
  const int N = 100;
  float readings[N];
  float sum = 0;
  
  Serial.print("Characterizing "); Serial.print(name);
  Serial.println(" — place 100mm from flat wall...");
  delay(2000);
  
  for (int i = 0; i < N; i++) {
    readings[i] = sensor.readRangeContinuousMillimeters();
    sum += readings[i];
    delay(20);
  }
  
  float mean = sum / N;
  float variance = 0;
  float minVal = readings[0], maxVal = readings[0];
  
  for (int i = 0; i < N; i++) {
    variance += (readings[i] - mean) * (readings[i] - mean);
    if (readings[i] < minVal) minVal = readings[i];
    if (readings[i] > maxVal) maxVal = readings[i];
  }
  
  float stddev = sqrt(variance / N);
  
  Serial.print(name); Serial.println(" Noise Analysis:");
  Serial.print("  Mean: "); Serial.print(mean, 1); Serial.println(" mm");
  Serial.print("  Std Dev: "); Serial.print(stddev, 2); Serial.println(" mm");
  Serial.print("  Min: "); Serial.print(minVal); Serial.println(" mm");
  Serial.print("  Max: "); Serial.print(maxVal); Serial.println(" mm");
  Serial.print("  Range: "); Serial.print(maxVal - minVal); Serial.println(" mm");
  
  if (stddev < 3.0) Serial.println("  Quality: EXCELLENT");
  else if (stddev < 8.0) Serial.println("  Quality: GOOD");
  else if (stddev < 15.0) Serial.println("  Quality: FAIR — consider median filter");
  else Serial.println("  Quality: POOR — check mounting, power, or replace sensor");
}

// Usage:
// characterizeSensorNoise(sensorFront, "Front");
// characterizeSensorNoise(sensorLeft, "Left");
// characterizeSensorNoise(sensorRight, "Right");
```

---

## Golden Reference Values

Typical known-good values for common N20 + VL53L0X micromouse setups. Use these as sanity checks:

| Parameter | Typical Value | Range | Unit |
|---|---|---|---|
| **Wheel diameter** | 34 | 30–40 | mm |
| **Wheelbase** | 70 | 60–80 | mm |
| **Encoder CPR** | 210 | 140–840 | counts/rev |
| **Kp_speed** | 2.5 | 1.5–4.0 | - |
| **Ki_speed** | 0.8 | 0.3–1.5 | - |
| **Kd_speed** | 0.1 | 0.05–0.2 | - |
| **Kp_straight** | 2.0 | 1.0–3.0 | - |
| **Exploration speed** | 120–150 | 80–180 | PWM (0–255) |
| **Turn speed** | 80–120 | 60–150 | PWM |
| **Speed run speed** | 180–220 | 150–255 | PWM |
| **Wall threshold** | 180 | 150–220 | mm |
| **VL53L0X noise (std dev)** | 2–5 | 1–10 | mm |
| **Gyro drift** | 0.3–0.8 | 0.1–1.5 | °/min |
| **Gyro bias (raw)** | ±10 | ±50 | LSB |
| **PID loop rate** | 50 | 50–200 | Hz |
| **I2C clock** | 400000 | 100000–400000 | Hz |
| **Motor stall current** | 0.5–1.0 | - | A |
| **Total robot weight** | 100 | 60–150 | g |

> [!TIP]
> If your values are wildly outside these ranges, something is probably misconfigured or miswired. Double-check before spending hours tuning.

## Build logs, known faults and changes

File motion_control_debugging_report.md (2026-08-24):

# Motion Control Debugging Report

I understand how frustrating it is when the robot just vibrates and stutters instead of moving. This report breaks down **exactly what was implemented**, **how the data flows**, and **the most likely reasons** for this failure so we can systematically fix it.

---

## 1. How the Control System is Currently Implemented

Every 1 millisecond (1kHz), the following chain of events happens in `Micromouse.ino` when you press `START`:

1. **State Machine (`Micromouse.ino`)**
   - Target Linear Velocity ($v$) is set to `150 mm/s`.
   - Target Heading is locked to whatever direction the robot is facing.
   - It calls `heading_controller_update()`.

2. **Heading PID (`heading_controller.cpp`)**
   - Compares Target Heading with Current IMU Heading.
   - Outputs an angular velocity correction, $\omega$ (omega). If the robot is perfectly straight, $\omega = 0$.

3. **Kinematics Engine (`velocity_controller.cpp`)**
   - Converts the robot's target $(v, \omega)$ into specific wheel targets:
     - $v_{left} = v - (\omega \times \text{WheelBase} / 2)$
     - $v_{right} = v + (\omega \times \text{WheelBase} / 2)$
   - Reads the raw encoder counts from the last 1 millisecond.
   - Multiplies the raw counts by 1000 to get counts/sec, converts to mm/s, and passes them through a **Low Pass Filter** to smooth out the jagged values.
   - Passes the target and current wheel speeds to the `speed_controller`.

4. **Wheel Speed PID (`speed_controller.cpp`)**
   - Applies **Feedforward**: Instantly guesses the required PWM. (`150 mm/s * 5.0 = 750 PWM`).
   - Applies **PID**: Looks at the error between the filtered target speed and current speed, and adjusts the PWM. (Currently $K_p = 2.0, K_i = 1.0$).
   - Calls `motor_set_both()` to physically drive the motors.

---

## 2. Most Likely Causes for the Violent Stuttering

Based on the symptoms (rapid start/stop, loud noise, no real forward movement), here are the absolute most likely culprits:

### Culprit A: Hardware Polarity Mismatch (Positive Feedback Loop)
This is the **#1 cause of this exact behavior in robotics**. 
If sending a **positive** PWM signal to drive the motor forward physically results in the encoder counting **backwards** (negative speed), the PID loop breaks completely.
* **What happens:** The PID wants `+150 mm/s`. It sends positive PWM. The robot moves forward, but the encoder reads `-50 mm/s`. The PID sees a massive error of `200 mm/s`. It sends *more* positive PWM. The encoder reads `-100 mm/s`. The PID violently maxes out the PWM at `4200` in a millisecond, triggering electrical noise or brownouts, and stuttering.

### Culprit B: IMU Vibration Feedback
The `heading_controller` relies on the IMU. N20 metal gear motors cause physical vibrations. If those vibrations are picked up by the MPU6050, the IMU heading rapidly fluctuates by a few degrees.
* **What happens:** The `heading_controller` sees the heading rapidly shifting left and right, so it violently swings the target angular velocity ($\omega$) between +5 and -5 rad/s. This commands the left and right wheels to rapidly alternate going extremely fast and extremely slow, resulting in a horrible stuttering noise.

### Culprit C: The Low-Pass Filter Lag
If the Low Pass Filter in the velocity controller is too aggressive ($\alpha = 0.05$), the speed reading is extremely smooth, but it is **delayed** by about 20-30 milliseconds.
* **What happens:** The PID applies power, but doesn't "see" the speed increase until 30ms later. It thinks the motor is stuck, so it pumps more power. 30ms later, the speed reading catches up and tells the PID it is going *way* too fast, so the PID slams on the brakes (negative PWM). This results in a heavy oscillation.

---

## 3. Step-by-Step Debugging Plan

To fix this, we must isolate the systems. You'll need to run a few tests and let me know the results.

### Step 1: Verify Feedforward (Open Loop Test)
We must ensure the motors can drive smoothly *without* the PID.
1. Open `src/control/speed_controller.cpp`.
2. Change the PID gains to exactly zero:
   ```cpp
   #define SPEED_KP 0.0f
   #define SPEED_KI 0.0f
   #define SPEED_KD 0.0f
   ```
3. Upload and press `START` on Phase 5.
**What to look for:** Does the robot drive forward smoothly (even if it drifts left/right)? If it still stutters, the problem is IMU Vibration (Culprit B). If it drives smoothly, we know the motors and PWM are fine.

### Step 2: Verify Encoder Polarity
We must ensure that physically pushing the robot forward results in POSITIVE speeds.
1. Change `p5_state == 0` (IDLE mode) in `Micromouse.ino` to print the raw encoder counts to the OLED.
2. Push the robot forward by hand. 
**What to look for:** Do both the Left and Right encoder counts go UP? If one or both go DOWN, we have Culprit A. We simply need to negate the output in `encoder_get_count()` / `encoder_get_delta()` for that wheel.

### Step 3: Disable Heading Controller (Isolate Wheels)
If the motors drive smoothly in Step 1, we must figure out if the IMU is causing the issue or the Speed PID.
1. Open `Micromouse.ino` line ~633 inside Phase 5.
2. Change `float omega = heading_controller_update(...)` to `float omega = 0.0f;`.
3. Put the PID gains back to `2.0` and `1.0`.
4. Upload and press `START`.
**What to look for:** Does it drive smoothly now? If yes, the `heading_controller` is the problem (IMU vibrations or bad heading PID tuning). If it still stutters violently, the Speed PID is the problem (Culprit C - filter lag).

Let me know which test you would like me to write the code for, or if you want to try editing the values yourself based on this report!

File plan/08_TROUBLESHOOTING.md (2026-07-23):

# 08 — Troubleshooting Guide

---

## Upload / Programming Issues

### "Cannot upload to STM32"
```
Problem: Arduino IDE can't find the board
Fix:
  1. Install STM32duino board package:
     File → Preferences → Board Manager URLs:
     https://github.com/stm32duino/BoardManagerFiles/raw/main/package_stmicroelectronics_index.json
  2. Tools → Board → STM32 Boards → Select correct board
  3. Tools → Upload Method → STLink (if using ST-Link V2)
  4. Check ST-Link V2 wiring: SWDIO, SWCLK, GND, 3.3V
```

### "STM32 board keeps resetting"
```
Fix: Check power supply is stable. Add 100µF cap on 3.3V rail.
     Also check BOOT0 pin — must be LOW (GND) for normal run mode.
```

### "Wire.begin() causes I2C lockup"
```
Fix for STM32 with STM32duino:
  Wire.begin(PB9, PB8);  // Must specify SDA, SCL for STM32
  Wire.setClock(400000);
  
  If still locking: add timeout recovery:
  Wire.setWireTimeout(3000, true);  // 3ms timeout, auto-reset
```

---

## Sensor Issues

### "VL53L0X not found" / I2C scan shows nothing
```
Checklist:
[ ] SDA and SCL wired to correct STM32 pins (PB9=SDA, PB8=SCL)?
[ ] 4.7kΩ pull-up resistors on SDA and SCL to 3.3V?
[ ] Sensor powered with 3.3V (not 5V)?
[ ] Wire.begin(PB9, PB8) called before sensor.init()?
[ ] XSHUT pin HIGH before calling init()?

I2C Scanner code:
  for (byte addr = 8; addr < 120; addr++) {
    Wire.beginTransmission(addr);
    if (Wire.endTransmission() == 0) {
      Serial.print("Found at 0x");
      Serial.println(addr, HEX);
    }
  }
```

### "Only first VL53L0X detected, others missing"
```
Problem: All sensors start at 0x29 — address collision
Fix: Follow XSHUT procedure in Stage 6 code exactly.
     Verify each XSHUT pin individually with multimeter.
     Check that you're calling sensor.setAddress() before
     enabling the next sensor.
```

### "VL53L0X reads 65535 or 8190 constantly"
```
65535 = timeout (no reading within time budget)
Fix:
  - Object too far (>1.2m) or no object in view
  - Increase timing budget: sensor.setMeasurementTimingBudget(33000)
  - Check sensor is not pointing at absorptive black surface
  - Check sensor lens is clean and unobstructed
```

### "MPU6050 yaw drifts rapidly"
```
Normal drift: < 1°/minute when still
Excessive drift causes:
  - Motor vibration transmitted to sensor
  - Mount MPU6050 on foam/rubber pad
  - Calibrate gyro bias at startup (see Stage 5)
  - Temperature change — recalibrate after warmup
  - Check AD0 pin — must be stable (not floating)
```

---

## Motor Issues

### "Motors don't move"
```
Checklist:
[ ] STBY pin HIGH?
[ ] Motor power (VM) connected to 7.4V?
[ ] Logic power (VCC) connected to 3.3V?
[ ] analogWrite() range — STM32 may default to 8-bit (0-255)
    Confirm with: analogWriteResolution(8); in setup()
[ ] PWM pin is actually a PWM-capable pin on your STM32?
```

### "One motor runs, other doesn't"
```
Test each motor channel independently with Stage 3 code.
Check BIN1/BIN2 wiring to correct TB6612FNG pins.
Check motor wires fully inserted into motor pads.
```

### "Motors stutter or vibrate instead of spinning smoothly"
```
Fix:
  - Increase PWM frequency (STM32 can do 20kHz):
    analogWriteFrequency(PWMA, 20000);  // (if supported by STM32duino version)
  - Check power supply — motor noise causing voltage drops
  - Add 100µF cap on VM pin of TB6612FNG
  - Check encoder ISR — if ISR is too slow, it blocks motor updates
```

### "Robot curves when it should go straight"
```
Causes:
  a) Different wheel diameters → measure and update code
  b) Different motor characteristics → PID will correct this
  c) One encoder giving wrong count → test encoders in Stage 4
  d) Straight-line correction gain too low → increase Kp_straight
  e) MPU6050 not centered on robot → reposition
```

---

## Encoder Issues

### "Encoder count stays at 0"
```
Fix:
  - Check encoder wires connected to correct STM32 interrupt pins
  - STM32 interrupt pins — most pins support interrupts on STM32F4
  - Check encoder VCC (some need 5V, check datasheet)
  - If 5V encoder, add voltage divider before STM32 pin
  - Test with: digitalRead(ENC_LA) → toggle manually
```

### "Encoder counts too high or inconsistent"
```
Fix:
  - Change from RISING to CHANGE interrupt to count all edges (×2 counts)
    or use RISING only and divide expected CPR by 2
  - Check for encoder wire bouncing → add 100nF cap between each encoder
    pin and GND (near the encoder connector)
```

---

## Power Issues

### "Robot resets when motors start"
```
Problem: Voltage sag on power supply when motors draw current
Fix:
  - Add 470µF–1000µF electrolytic cap on 7.4V rail (near TB6612FNG)
  - Add 100µF on 5V rail
  - Check buck converter current rating ≥ 1A
  - Separate motor power and logic power with LC filter or ferrite bead
```

### "Sensors reset or give garbage when motors run"
```
Problem: Motor PWM EMI coupling into I2C bus
Fix:
  - Route I2C traces/wires away from motor/PWM traces
  - Reduce PWM frequency to 1kHz (less interference) or increase to 20kHz (above I2C)
  - Add 100nF cap on each sensor VCC pin
  - Twist I2C wire pair together
```

### "Battery drains in <5 minutes"
```
Check:
  - Battery capacity (mAh) — use 500mAh minimum
  - Motor stall — if wheels blocked, current skyrockets
  - Check current draw: multimeter in series at startup
    Normal idle: ~200mA
    Normal running: ~400–600mA
    Stalled: >1A → add stall detection
```

---

## Algorithm Issues

### "Robot goes in circles / doesn't reach goal"
```
Debug flood fill:
  Print floodValues array to Serial:
  for (int y = MAZE_SIZE-1; y >= 0; y--) {
    for (int x = 0; x < MAZE_SIZE; x++) {
      Serial.print(floodValues[x][y]); Serial.print("\t");
    }
    Serial.println();
  }
  Check: does value decrease toward goal cells?
```

### "Robot maps walls incorrectly"
```
Debug:
  - Print walls[][] array after each cell visit
  - Check sensor → absolute direction conversion
  - Verify robotHeading updates correctly after turns
  - Verify dx/dy arrays match your heading convention
```

### "Robot tries to go through walls"
```
Fix:
  - Wall thresholds too high (reads "no wall" when wall is present)
  - Lower WALL_PRESENT_THRESHOLD or increase sensor gain
  - Check sensor physical angle — must point at wall, not floor
  - Add extra confirmation: read sensor 3× and take minimum
```

---

## Quick Debug Commands (Serial Monitor)

Add these to your code for easy debugging:
```cpp
void printMazeState() {
  Serial.print("Pos: (");
  Serial.print(robotX); Serial.print(",");
  Serial.print(robotY); Serial.print(") Heading: ");
  const char* dirs[] = {"N","E","S","W"};
  Serial.println(dirs[robotHeading]);
  
  SensorData s = readSensors();
  Serial.print("Sensors F/L/R: ");
  Serial.print(s.front); Serial.print("/");
  Serial.print(s.left); Serial.print("/");
  Serial.println(s.right);
  
  Serial.print("Flood value here: ");
  Serial.println(floodValues[robotX][robotY]);
  
  Serial.print("Battery: ");
  Serial.print(readBatteryVoltage(), 2);
  Serial.println("V");
}
```

---

## I2C Bus Recovery

### "I2C bus locked / SDA stuck low"
```
Problem: A sensor crashed mid-transaction and is holding SDA low.
This prevents all I2C communication.

Automatic recovery code:
```

```cpp
void i2cRecover() {
  // Temporarily release I2C
  Wire.end();
  
  // Manually toggle SCL 9 times to free stuck SDA
  pinMode(PB8, OUTPUT);  // SCL pin
  pinMode(PB9, INPUT);   // SDA pin — check state
  
  for (int i = 0; i < 9; i++) {
    digitalWrite(PB8, LOW);
    delayMicroseconds(5);
    digitalWrite(PB8, HIGH);
    delayMicroseconds(5);
    
    // Check if SDA is released
    if (digitalRead(PB9) == HIGH) {
      Serial.print("I2C recovered after ");
      Serial.print(i + 1);
      Serial.println(" clock pulses.");
      break;
    }
  }
  
  // Generate STOP condition
  pinMode(PB9, OUTPUT);
  digitalWrite(PB9, LOW);
  delayMicroseconds(5);
  digitalWrite(PB8, HIGH);
  delayMicroseconds(5);
  digitalWrite(PB9, HIGH);
  delayMicroseconds(5);
  
  // Re-initialize I2C
  Wire.begin(PB9, PB8);
  Wire.setClock(400000);
}

// Call this if a sensor read returns 65535 multiple times in a row:
// if (consecutiveTimeouts > 3) i2cRecover();
```

### Prevention tips:
- Set I2C timeout: `Wire.setWireTimeout(3000, true);` (3ms timeout, auto-reset)
- Use hardware watchdog (see `06_MAIN_LOGIC_CODE.md`)
- Add 100nF bypass cap on every sensor VCC pin

---

## Robot Tipping / Flipping Over

### "Robot tips forward during braking"
```
Problem: Center of gravity is too high or too far forward.

Fix:
  1. Move battery to the rear — it's the heaviest component
  2. Lower overall height — keep under 60mm
  3. Reduce deceleration rate in moveForward():
     - Change: int speed = (progress > 0.8) ? 80 : baseSpeed;
     - To:     int speed = baseSpeed * (1.0 - progress * 0.7);
       This creates a linear deceleration instead of sudden drop.
  4. Add ball caster with appropriate height matching
  5. Consider wider wheelbase (>70mm) for more stability
```

### "Robot wheelies during acceleration"
```
Fix:
  - Reduce acceleration rate (don't jump from 0 to 200 PWM)
  - Implement trapezoidal velocity profile (ramp up speed gradually)
  - Move battery forward slightly to balance weight
  - Lower center of gravity
```

### Center of gravity check:
```
1. Balance robot on a pencil placed widthwise
2. The balance point should be near the wheel axle line
3. If it tips forward → move battery back
4. If it tips backward → move battery forward
```

---

## STM32 Crash / HardFault Debugging

### "Robot suddenly stops and LED freezes"
```
Problem: STM32 entered a HardFault — usually caused by:
  - Null pointer dereference
  - Stack overflow (too many local variables in recursive functions)
  - Division by zero
  - Invalid memory access
```

### HardFault Handler (add to your code):
```cpp
// This replaces the default HardFault handler with one that gives debug info

extern "C" void HardFault_Handler(void) {
  // Read fault status registers
  volatile uint32_t hfsr = SCB->HFSR;
  volatile uint32_t cfsr = SCB->CFSR;
  volatile uint32_t mmfar = SCB->MMFAR;
  volatile uint32_t bfar = SCB->BFAR;
  
  // Try to output debug info (may not work if UART is broken)
  Serial.println("\n\n!!! HARD FAULT !!!");
  Serial.print("HFSR:  0x"); Serial.println(hfsr, HEX);
  Serial.print("CFSR:  0x"); Serial.println(cfsr, HEX);
  Serial.print("MMFAR: 0x"); Serial.println(mmfar, HEX);
  Serial.print("BFAR:  0x"); Serial.println(bfar, HEX);
  Serial.flush();
  
  // Blink LED rapidly to signal crash
  pinMode(PC13, OUTPUT);
  while (1) {
    digitalWrite(PC13, LOW);
    for (volatile int i = 0; i < 100000; i++);
    digitalWrite(PC13, HIGH);
    for (volatile int i = 0; i < 100000; i++);
  }
}
```

### Common causes and fixes:

| CFSR Bit | Meaning | Likely Cause | Fix |
|---|---|---|-----|
| Bit 25 (DIVBYZERO) | Division by zero | `dt = 0` in PID calculation | Add `if (dt < 0.001) return;` guard |
| Bit 16 (UNDEFINSTR) | Undefined instruction | Corrupt flash or bad jump | Re-flash firmware |
| Bit 1 (DACCVIOL) | Data access violation | Bad pointer or array overflow | Check array bounds |
| Bit 0 (IACCVIOL) | Instruction access violation | Stack overflow | Reduce local variables, avoid deep recursion |

### Stack overflow prevention:
```
- Don't use large local arrays in functions called from ISRs
- The flood fill BFS uses std::queue which allocates on heap —
  ensure heap is large enough (default 8KB on STM32F401 is usually fine)
- Monitor stack usage: add canary values at the bottom of stack
```

---

## Emergency Recovery Procedure

If your robot is stuck in a bad state and you can't upload new code:

```
1. Hold BOOT0 button while pressing RESET → enters DFU mode
2. In Arduino IDE: Tools → Upload Method → STM32CubeProgrammer (DFU)
3. Flash a simple blink sketch to verify MCU is alive
4. Then re-flash your micromouse code

Alternative: Use ST-Link to force-flash — always works regardless of firmware state.
```

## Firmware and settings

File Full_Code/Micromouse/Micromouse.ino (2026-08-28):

/**
 * @file Micromouse.ino
 * @brief Main Arduino sketch for the Micromouse.
 *
 * This is the main entry point for the Arduino framework. It initializes
 * all hardware and software modules, then hands over execution to the
 * robot state machine in the main loop.
 */

#include <Arduino.h>
#include <Wire.h>

#include "src/config/pin_config.h"
#include "src/config/robot_config.h"

// Hardware
#include "src/hardware/battery.h"
#include "src/hardware/button.h"
#include "src/hardware/encoder.h"
#include "src/hardware/gpio.h"
#include "src/hardware/led.h"
#include "src/hardware/motor.h"
#include "src/hardware/pwm.h"
#include "src/hardware/timer.h"

// Sensors
#include "src/sensors/calibration.h"
#include "src/sensors/distance_manager.h"
#include "src/sensors/mpu6050.h"
#include "src/sensors/sensor_fusion.h"
#include "src/sensors/sensor_manager.h"

// Localization
#include "src/localization/odometry.h"
#include "src/localization/position_estimator.h"

// Control
#include "src/control/heading_controller.h"
#include "src/control/motion_controller.h"
#include "src/control/speed_controller.h"
#include "src/control/velocity_controller.h"

// Robot
#include "src/robot/mission_manager.h"
#include "src/robot/robot_state_machine.h"

// Display
#include "src/display/menu.h"
#include "src/display/oled_driver.h"
#include "src/display/status_screen.h"

// Utils
#include "src/utils/debug_buffer.h"
#include "src/utils/logger.h"
#include "src/utils/serial_debug.h"

// Phase testing mode flags (set to 1 for active test mode)
#define PHASE_1_TEST_MODE 0
#define PHASE_2_TEST_MODE 0
#define PHASE_3_TEST_MODE 0
#define PHASE_4_TEST_MODE 0
#define PHASE_5_TEST_MODE 1

#if PHASE_1_TEST_MODE == 1
volatile uint32_t phase1_timer_ticks = 0;
void phase1_timer_callback(void) { phase1_timer_ticks++; }
#endif

#if PHASE_2_TEST_MODE == 1
volatile uint32_t phase2_timer_ticks = 0;
void phase2_timer_callback(void) { phase2_timer_ticks++; }
#endif

#if PHASE_3_TEST_MODE == 1
volatile uint32_t phase3_timer_ticks = 0;
void phase3_timer_callback(void) { phase3_timer_ticks++; }
#endif

#if PHASE_4_TEST_MODE == 1
volatile uint32_t phase4_timer_ticks = 0;
void phase4_timer_callback(void) { phase4_timer_ticks++; }
#endif

void setup() {
  Serial.begin(115200);
  delay(100);
  LOG_INFO("Micromouse Booting...");

#if PHASE_1_TEST_MODE == 1
  LOG_INFO("=== PHASE 1 HARDWARE TEST MODE ===");
  gpio_init_motor_pins();
  button_init();
  led_init();
  battery_init();

  Wire.setSCL(PIN_I2C_SCL);
  Wire.setSDA(PIN_I2C_SDA);
  Wire.begin();
  Wire.setClock(400000);
  if (oled_init()) {
    oled_clear();
    oled_print(0, 0, "Phase 1 Test Mode");
    oled_update();
  } else {
    LOG_ERROR("OLED Init Failed");
  }

  uint16_t v_mv = battery_get_voltage_mv();
  uint8_t v_pct = battery_get_percentage();
  Serial.print("Battery Voltage: ");
  Serial.print(v_mv);
  Serial.print(" mV (");
  Serial.print(v_pct);
  Serial.println("%)");

  // Test non-blocking LED blinking on status LED (250ms interval)
  led_blink(LED_STATUS, 250);

  // Initialize timer with 1kHz test callback
  timer_init(phase1_timer_callback);
  timer_start();
  LOG_INFO("Press BTN_START to test debug LED, BTN_MODE to toggle status LED.");
  return;
#endif

#if PHASE_2_TEST_MODE == 1
  LOG_INFO("=== PHASE 2 ACTUATION & ENCODER TEST MODE ===");
  gpio_init_motor_pins();
  pwm_init();
  encoder_init();
  motor_init();
  button_init();
  led_init();
  battery_init();

  Wire.setSCL(PIN_I2C_SCL);
  Wire.setSDA(PIN_I2C_SDA);
  Wire.begin();
  Wire.setClock(400000);
  if (oled_init()) {
    oled_clear();
    oled_print(0, 0, "Phase 2 Test Mode");
    oled_update();
  } else {
    LOG_ERROR("OLED Init Failed");
  }

  // Reset encoders to zero
  encoder_reset_all();

  // Start 1kHz control loop timer
  timer_init(phase2_timer_callback);
  timer_start();

  LOG_INFO("Phase 2 Ready!");
  LOG_INFO(" - Press BTN_START to cycle motor states (Stop -> Fwd -> Rev -> "
           "TurnL -> TurnR -> Stop).");
  LOG_INFO(" - Press BTN_MODE to zero/reset encoders.");
  return;
#endif

#if PHASE_3_TEST_MODE == 1
  LOG_INFO("=== PHASE 3 SENSING TEST MODE ===");
  button_init();
  led_init();
  battery_init();

  Wire.setSCL(PIN_I2C_SCL);
  Wire.setSDA(PIN_I2C_SDA);
  Wire.begin();
  Wire.setClock(400000);
  if (oled_init()) {
    oled_clear();
    oled_print(0, 0, "Phase 3 Booting");
    oled_update();
  } else {
    LOG_ERROR("OLED Init Failed");
  }

  // Initialize Sensors
  sensor_manager_init();

  // Calibrate Gyro
  calibrate_all();

  // Start 1kHz control loop timer
  timer_init(phase3_timer_callback);
  timer_start();

  LOG_INFO("Phase 3 Ready!");
  LOG_INFO(" - BTN_START: Re-calibrate Gyro");
  LOG_INFO(" - BTN_MODE: Toggle Debug LED");
  return;
#endif

#if PHASE_4_TEST_MODE == 1
  LOG_INFO("=== PHASE 4 SENSOR FUSION TEST MODE ===");
  button_init();
  led_init();
  battery_init();
  encoder_init();

  Wire.setSCL(PIN_I2C_SCL);
  Wire.setSDA(PIN_I2C_SDA);
  Wire.begin();
  Wire.setClock(400000);
  if (oled_init()) {
    oled_clear();
    oled_print(0, 0, "Phase 4 Booting");
    oled_update();
  }

  sensor_manager_init();
  calibrate_all();
  fusion_init();

  timer_init(phase4_timer_callback);
  timer_start();

  LOG_INFO("Phase 4 Ready!");
  return;
#endif

#if PHASE_5_TEST_MODE == 1
  LOG_INFO("=== PHASE 5 TEST MODE ===");
  gpio_init_motor_pins();
  pwm_init();
  encoder_init();
  motor_init();
  button_init();
  led_init();
  battery_init();

  Wire.setSCL(PIN_I2C_SCL);
  Wire.setSDA(PIN_I2C_SDA);
  Wire.begin();
  Wire.setClock(400000);
  if (oled_init()) {
    oled_clear();
    oled_print(0, 0, "Phase 5");
    oled_update();
  }

  sensor_manager_init();
  calibrate_all();

  LOG_INFO("Phase 5 Ready!");
  LOG_INFO("Press START to begin Wall Following test.");
  return;
#endif

  // 1. Hardware Initialization (Motors, Pins, Encoders, Battery, etc.)
  gpio_init_motor_pins();
  pwm_init();
  encoder_init();
  motor_init();
  button_init();
  led_init();
  battery_init();

  // 2. Display Initialization
  Wire.begin();
  Wire.setClock(400000); // 400kHz I2C
  if (oled_init()) {
    oled_clear();
    oled_print(0, 0, "Micromouse v1.0");
    oled_update();
  } else {
    LOG_ERROR("OLED init failed!");
  }

  // 3. Sensor Initialization (VL53L0X & MPU6050)
  // Note: XSHUT pins are toggled inside sensor_manager_init()
  // to change I2C addresses dynamically.
  sensor_manager_init();

  // Optional Gyro Calibration Phase (from plan)
  LOG_INFO("Calibrating Gyro - Keep Robot Still");
  // calibrateGyro(); // Assume integrated in fusion_init or sensor_manager

  // Hardware I2C Watchdog Setup (from plan)
  // setupWatchdog();

  // 4. Software Modules Initialization
  odometry_init();
  fusion_init();
  motion_controller_init();
  mission_manager_init();
  menu_init();
  fsm_init();

  // 5. Maze Array Initialization (from plan)
  /*
  memset(walls, 0, sizeof(walls));
  memset(visited, 0, sizeof(visited));
  for (int i = 0; i < MAZE_SIZE; i++) {
      walls[0][i]           |= 8;  // West border
      walls[MAZE_SIZE-1][i] |= 2;  // East border
      walls[i][0]           |= 4;  // South border
      walls[i][MAZE_SIZE-1] |= 1;  // North border
  }
  floodFill();
  */

  // 6. Start Control Loop Interrupt
  timer_init(motion_controller_update);
  timer_start();

  // 7. Wait for Start Button (from plan)
  LOG_INFO("Press BTN_START to begin exploration.");
  // Wait until button is pressed before engaging exploration
  // while(button_read() == false) { delay(10); }
  // delay(500);

  // 8. Enter Initial State
  fsm_set_state(STATE_IDLE);
  LOG_INFO("Boot Complete. Entering Idle/Exploring.");
}

void loop() {
#if PHASE_1_TEST_MODE == 1
  button_update();
  led_update();

  // Test button 0 (BUTTON_START)
  if (button_just_pressed(BUTTON_START)) {
    LOG_INFO("BTN_START Pressed! Toggling debug LED.");
    led_toggle(LED_DEBUG);
  }

  // Test button 1 (BUTTON_MODE)
  if (button_just_pressed(BUTTON_MODE)) {
    LOG_INFO("BTN_MODE Pressed! Toggling status LED.");
    led_toggle(LED_STATUS);
  }

  // Print timer heartbeat and battery status every 1000 ticks (~1 second)
  static uint32_t last_print_ticks = 0;
  if ((phase1_timer_ticks - last_print_ticks) >= 1000) {
    last_print_ticks = phase1_timer_ticks;

    char buf[32];
    oled_clear();
    oled_print(0, 0, "Phase 1 Test");
    sprintf(buf, "Ticks: %lu", phase1_timer_ticks);
    oled_print(0, 16, buf);
    sprintf(buf, "Bat: %u mV", battery_get_voltage_mv());
    oled_print(0, 32, buf);
    oled_update();

    Serial.print("[Heartbeat 1Hz] Timer Ticks: ");
    Serial.print(phase1_timer_ticks);
    Serial.print(" | Battery: ");
    Serial.print(battery_get_voltage_mv());
    Serial.println(" mV");
  }

  delay(5);
  return;
#endif

#if PHASE_2_TEST_MODE == 1
  button_update();
  led_update();

  static int test_state = 0;
  if (button_just_pressed(BUTTON_START)) {
    test_state = (test_state + 1) % 6;
    switch (test_state) {
    case 0:
      motor_stop();
      LOG_INFO("[State 0] Motors STOPPED.");
      break;
    case 1:
      motor_forward(1500);
      LOG_INFO("[State 1] Motors FORWARD (PWM 1500).");
      break;
    case 2:
      motor_reverse(1500);
      LOG_INFO("[State 2] Motors REVERSE (PWM 1500).");
      break;
    case 3:
      motor_turn_left(1500);
      LOG_INFO("[State 3] Motors TURN LEFT (PWM 1500).");
      break;
    case 4:
      motor_turn_right(1500);
      LOG_INFO("[State 4] Motors TURN RIGHT (PWM 1500).");
      break;
    case 5:
      motor_stop();
      LOG_INFO("[State 5] Motors STOPPED.");
      break;
    }
    led_toggle(LED_DEBUG);
  }

  if (button_just_pressed(BUTTON_MODE)) {
    encoder_reset_all();
    LOG_INFO("Encoders Reset to 0!");
    led_toggle(LED_STATUS);
  }

  static uint32_t last_enc_print = 0;
  if ((phase2_timer_ticks - last_enc_print) >= 500) {
    last_enc_print = phase2_timer_ticks;

    // 1. Get absolute positions
    int32_t l_cnt = encoder_get_count(ENCODER_LEFT);
    int32_t r_cnt = encoder_get_count(ENCODER_RIGHT);
    float l_mm = encoder_counts_to_mm(l_cnt);
    float r_mm = encoder_counts_to_mm(r_cnt);

    // 2. Get deltas to calculate speed
    // This block runs every 500ms (0.5s), so multiply delta by 2 for
    // counts_per_sec
    int32_t l_delta = encoder_get_delta(ENCODER_LEFT);
    int32_t r_delta = encoder_get_delta(ENCODER_RIGHT);

    float l_speed = encoder_counts_to_speed(l_delta * 2.0f);
    float r_speed = encoder_counts_to_speed(r_delta * 2.0f);

    // Update OLED
    char buf[32];
    oled_clear();
    oled_print(0, 0, "- Phase 2 Test -");

    sprintf(buf, "Spd L: %d mm/s", (int)l_speed);
    oled_print(0, 15, buf);

    sprintf(buf, "Spd R: %d mm/s", (int)r_speed);
    oled_print(0, 25, buf);

    sprintf(buf, "Cnt L:%ld R:%ld", l_cnt, r_cnt);
    oled_print(0, 40, buf);

    sprintf(buf, "Dst L:%d R:%d", (int)l_mm, (int)r_mm);
    oled_print(0, 50, buf);

    oled_update();

    Serial.print("[Phase 2 2Hz] L: ");
    Serial.print(l_mm, 1);
    Serial.print("mm, ");
    Serial.print(l_speed, 1);
    Serial.print("mm/s | R: ");
    Serial.print(r_mm, 1);
    Serial.print("mm, ");
    Serial.print(r_speed, 1);
    Serial.println("mm/s");
  }

  delay(5);
  return;
#endif

#if PHASE_3_TEST_MODE == 1
  button_update();
  led_update();

  if (button_just_pressed(BUTTON_START)) {
    LOG_INFO("Re-calibrating Gyro...");
    calibrate_all();
  }

  if (button_just_pressed(BUTTON_MODE)) {
    led_toggle(LED_DEBUG);
  }

  static uint32_t last_sensor_print = 0;
  // Update sensors every 100ms (10Hz)
  if ((phase3_timer_ticks - last_sensor_print) >= 100) {
    last_sensor_print = phase3_timer_ticks;

    sensor_manager_update();

    IMUScaledData imu;
    mpu6050_read_scaled(&imu);

    uint16_t dist_f = distance_get_mm(TOF_FRONT);
    uint16_t dist_fl = distance_get_mm(TOF_FRONT_LEFT);
    uint16_t dist_fr = distance_get_mm(TOF_FRONT_RIGHT);
    uint16_t dist_l = distance_get_mm(TOF_LEFT);
    uint16_t dist_r = distance_get_mm(TOF_RIGHT);

    char buf[32];
    oled_clear();
    oled_print(0, 0, "- Phase 3 Test -");

    sprintf(buf, "F:%u FL:%u FR:%u", dist_f, dist_fl, dist_fr);
    oled_print(0, 15, buf);

    sprintf(buf, "L:%u R:%u", dist_l, dist_r);
    oled_print(0, 25, buf);

    String gyroStr = String(imu.gyro_z_dps, 1);
    sprintf(buf, "GyroZ: %s deg/s", gyroStr.c_str());
    oled_print(0, 40, buf);

    sprintf(buf, "Bat: %u mV", battery_get_voltage_mv());
    oled_print(0, 50, buf);

    oled_update();

    Serial.print("[Phase3] F:");
    Serial.print(dist_f);
    Serial.print(" FL:");
    Serial.print(dist_fl);
    Serial.print(" FR:");
    Serial.print(dist_fr);
    Serial.print(" L:");
    Serial.print(dist_l);
    Serial.print(" R:");
    Serial.print(dist_r);
    Serial.print(" | Gz:");
    Serial.print(imu.gyro_z_dps, 1);
    Serial.print(" | Bat:");
    Serial.print(battery_get_voltage_mv());
    Serial.print(" | BiasZ:");
    Serial.print(mpu6050_get_gyro_bias_z(), 1);

    IMURawData raw;
    mpu6050_read_raw(&raw);
    Serial.print(" | RawZ:");
    Serial.println(raw.gyro_z);
  }

  delay(5);
  return;
#endif

#if PHASE_4_TEST_MODE == 1
  button_update();
  led_update();

  static uint32_t last_sensor_tick = millis();
  if (millis() - last_sensor_tick >= 10) {
    last_sensor_tick = millis();
    // Thanks to Round-Robin polling, this only takes ~30ms now!
    // It is totally safe to run alongside the gyro.
    sensor_manager_update();
  }

  // Sensor fusion update (Throttled to 100Hz)
  static uint32_t last_fusion_tick = millis();
  if (millis() - last_fusion_tick >= 10) {
    uint32_t now = millis();
    float dt = (now - last_fusion_tick) / 1000.0f;
    last_fusion_tick = now;

    // Guard against backward time
    if (dt <= 0.0f) {
      dt = 0.01f;
    }

    fusion_update(dt);
  }

  static uint32_t last_print = 0;
  if (millis() - last_print >= 100) {
    last_print = millis();
    Pose p = position_estimator_get_pose();

    char buf[32];
    oled_clear();
    oled_print(0, 0, "- Phase 4 -");

    // Also add button functionality to reset the pose
    if (button_is_pressed(BUTTON_MODE)) {
      fusion_reset_heading(0.0f);
      Pose zero = {0.0f, 0.0f, 0.0f};
      odometry_set_pose(zero);
    }

    sprintf(buf, "X: %d mm", (int)p.x_mm);
    oled_print(0, 15, buf);

    sprintf(buf, "Y: %d mm", (int)p.y_mm);
    oled_print(0, 25, buf);

    float deg = p.theta_rad * (180.0f / 3.14159265f);
    sprintf(buf, "H: %d deg", (int)deg);
    oled_print(0, 40, buf);

    oled_update();

    Serial.print("[Phase4] X: ");
    Serial.print(p.x_mm, 1);
    Serial.print(" mm | Y: ");
    Serial.print(p.y_mm, 1);
    Serial.print(" mm | H: ");
    Serial.print(deg, 1);
    Serial.println(" deg");
  }
  delay(5);
  return;
#endif
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

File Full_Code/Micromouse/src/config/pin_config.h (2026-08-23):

/**
 * @file pin_config.h
 * @brief Centralized pin assignment map for the Micromouse robot.
 *
 * All hardware pin definitions live here. Every module that touches a
 * physical pin must include this file instead of hard-coding pin numbers.
 *
 * Platform: STM32F401CCU6 (Black Pill)
 * Framework: Arduino Core for STM32
 */

#ifndef PIN_CONFIG_H
#define PIN_CONFIG_H

/* ═══════════════════════════════════════════════════════════════════════════
 *  Motor Driver — TB6612FNG
 * ═══════════════════════════════════════════════════════════════════════════ */

/** @defgroup MotorPins Motor Driver Pin Assignments
 *  TB6612FNG H-bridge motor driver connections.
 *  @{
 */

/* Left Motor (Motor B - Swapped to fix physical wiring) */
#define PIN_MOTOR_LEFT_PWM      PA9     /**< TIM1_CH2 — Left motor PWM      */
#define PIN_MOTOR_LEFT_IN1      PB15    /**< BIN1 — Left motor direction 1  */
#define PIN_MOTOR_LEFT_IN2      PA10    /**< BIN2 — Left motor direction 2  */

/* Right Motor (Motor A - Swapped to fix physical wiring) */
#define PIN_MOTOR_RIGHT_PWM     PA8     /**< TIM1_CH1 — Right motor PWM     */
#define PIN_MOTOR_RIGHT_IN1     PB13    /**< AIN1 — Right motor direction 1 */
#define PIN_MOTOR_RIGHT_IN2     PB12    /**< AIN2 — Right motor direction 2 */

/* Standby */
#define PIN_MOTOR_STBY          PB14    /**< STBY — Motor driver enable     */

/** @} */ // end MotorPins

/* ═══════════════════════════════════════════════════════════════════════════
 *  Encoders — Quadrature (Hardware Timer Encoder Mode)
 * ═══════════════════════════════════════════════════════════════════════════ */

/** @defgroup EncoderPins Encoder Pin Assignments
 *  N20 motor quadrature encoder connections.
 *  @{
 */

/* Left Encoder — TIM2 (32-bit timer) */
#define PIN_ENC_LEFT_A          PA0     /**< TIM2_CH1 — Left encoder A      */
#define PIN_ENC_LEFT_B          PA1     /**< TIM2_CH2 — Left encoder B      */

/* Right Encoder — TIM3 (16-bit timer) */
#define PIN_ENC_RIGHT_A         PA6     /**< TIM3_CH1 — Right encoder A     */
#define PIN_ENC_RIGHT_B         PA7     /**< TIM3_CH2 — Right encoder B     */

/** @} */ // end EncoderPins

/* ═══════════════════════════════════════════════════════════════════════════
 *  I2C Bus — Shared (MPU6050, SSD1306, VL53L0x)
 * ═══════════════════════════════════════════════════════════════════════════ */

/** @defgroup I2CPins I2C Bus Pin Assignments
 *  Shared I2C1 bus for all I2C peripherals.
 *  @{
 */

#define PIN_I2C_SCL             PB8     /**< I2C1_SCL                       */
#define PIN_I2C_SDA             PB9     /**< I2C1_SDA                       */
#define I2C_CLOCK_SPEED         400000  /**< I2C Fast Mode (400kHz)         */

/** @} */ // end I2CPins

/* ═══════════════════════════════════════════════════════════════════════════
 *  IMU — MPU6050
 * ═══════════════════════════════════════════════════════════════════════════ */

/** @defgroup IMUPins IMU Pin Assignments
 *  MPU6050 6-axis IMU on the shared I2C bus.
 *  @{
 */

#define MPU6050_I2C_ADDR        0x68    /**< Default I2C address (AD0=LOW)  */

/** @} */ // end IMUPins

/* ═══════════════════════════════════════════════════════════════════════════
 *  OLED — SSD1306 (128×64)
 * ═══════════════════════════════════════════════════════════════════════════ */

/** @defgroup OLEDPins OLED Pin Assignments
 *  SSD1306 128×64 OLED on the shared I2C bus.
 *  @{
 */

#define SSD1306_I2C_ADDR        0x3C    /**< Default I2C address            */
#define OLED_WIDTH              128     /**< Display width in pixels        */
#define OLED_HEIGHT             64      /**< Display height in pixels       */

/** @} */ // end OLEDPins

/* ═══════════════════════════════════════════════════════════════════════════
 *  ToF Distance Sensors — VL53L0X (×5)
 * ═══════════════════════════════════════════════════════════════════════════ */

/** @defgroup ToFPins VL53L0X XSHUT Pin Assignments
 *  Each VL53L0X sensor has an XSHUT pin for I2C address reassignment.
 *  All sensors share the same I2C bus; XSHUT is used to bring them
 *  online one at a time during initialization and assign unique addresses.
 *  @{
 */

/* Assigned XSHUT pins based on wiring plan */
#define PIN_TOF_XSHUT_FRONT         PA4     /**< Front sensor XSHUT               */
#define PIN_TOF_XSHUT_FRONT_LEFT    PB1     /**< Front-left (L-45°) sensor XSHUT  */
#define PIN_TOF_XSHUT_FRONT_RIGHT   PC14    /**< Front-right (R-45°) sensor XSHUT */
#define PIN_TOF_XSHUT_LEFT          PA15    /**< Left (L-90°) sensor XSHUT        */
#define PIN_TOF_XSHUT_RIGHT         PB3     /**< Right (R-90°) sensor XSHUT       */
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

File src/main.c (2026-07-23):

/**
 * @file main.c
 * @brief Desktop test harness — runs the full micromouse algorithm suite
 *        on a hardcoded maze and prints results.
 *
 * Compile:  gcc -o maze_test main.c flood_fill.c dijkstra_weighted.c path_smoother.c solver.c -lm
 * Run:      ./maze_test
 */

#include <stdio.h>
#include <stdlib.h>
#include <string.h>
#include "solver.h"
#include "motion_profile.h"

/* ═══════════════════════════════════════════════════════════════════════════
 *  Test Maze Builder
 *
 *  Builds a realistic competition-style 16×16 maze with corridors,
 *  dead ends, and multiple paths to the center.
 * ═══════════════════════════════════════════════════════════════════════════ */

static void build_test_maze(MazeMap *m)
{
    maze_init_unknown(m);

    /* Wall format: {x, y, direction} */
    typedef struct { uint8_t x, y; Direction d; } W;
    const W walls[] = {
        /* Start area corridors */
        {0,0, DIR_EAST},  {1,0, DIR_EAST},  {2,0, DIR_NORTH},
        {0,1, DIR_EAST},  {0,2, DIR_EAST},
        {1,1, DIR_NORTH}, {2,1, DIR_EAST},  {3,1, DIR_NORTH},
        {3,0, DIR_NORTH}, {4,0, DIR_EAST},  {5,0, DIR_NORTH},
        {5,1, DIR_NORTH},

        /* Central structure */
        {3,2, DIR_EAST},  {4,2, DIR_NORTH}, {4,3, DIR_EAST},
        {5,3, DIR_NORTH}, {6,2, DIR_NORTH}, {6,3, DIR_EAST},
        {7,3, DIR_NORTH}, {2,3, DIR_NORTH}, {2,4, DIR_EAST},
        {3,4, DIR_NORTH}, {3,5, DIR_EAST},  {4,5, DIR_NORTH},
        {5,5, DIR_EAST},  {6,5, DIR_NORTH}, {6,6, DIR_EAST},

        /* Goal area walls */
        {7,6, DIR_NORTH}, {8,6, DIR_NORTH}, {7,8, DIR_EAST},
        {8,8, DIR_NORTH}, {6,7, DIR_NORTH}, {9,7, DIR_NORTH},
        {9,8, DIR_EAST},

        /* Upper corridors */
        {2,6, DIR_EAST},  {3,6, DIR_NORTH}, {4,7, DIR_EAST},
        {5,7, DIR_NORTH}, {1,5, DIR_NORTH}, {1,6, DIR_EAST},
        {0,7, DIR_EAST},

        /* Right side */
        {10,3, DIR_NORTH}, {11,3, DIR_EAST}, {11,4, DIR_NORTH},
        {10,5, DIR_EAST},  {11,5, DIR_NORTH},{12,5, DIR_EAST},
        {10,7, DIR_NORTH}, {11,7, DIR_EAST}, {12,7, DIR_NORTH},

        /* Far side */
        {13,2, DIR_NORTH}, {14,2, DIR_EAST}, {13,4, DIR_NORTH},
        {14,4, DIR_EAST},  {13,6, DIR_NORTH},{14,6, DIR_EAST},
        {13,8, DIR_NORTH}, {14,8, DIR_EAST},
        {12,9, DIR_NORTH}, {13,9, DIR_EAST}, {12,10, DIR_EAST},
        {10,10, DIR_NORTH},{11,10, DIR_EAST},{10,11, DIR_NORTH},
        {8,10, DIR_NORTH}, {9,10, DIR_EAST}, {8,11, DIR_EAST},

        /* Upper maze */
        {2,9, DIR_EAST},   {3,9, DIR_NORTH}, {4,9, DIR_EAST},
        {5,10, DIR_NORTH}, {6,10, DIR_EAST}, {7,10, DIR_NORTH},
        {6,11, DIR_NORTH}, {3,11, DIR_EAST}, {4,11, DIR_NORTH},
        {5,12, DIR_EAST},  {2,12, DIR_NORTH},{1,12, DIR_EAST},
        {0,11, DIR_NORTH}, {7,12, DIR_NORTH},{8,12, DIR_EAST},
        {9,12, DIR_NORTH}, {10,12, DIR_EAST},{11,13, DIR_NORTH},
        {12,12, DIR_NORTH},{13,12, DIR_EAST},{14,12, DIR_NORTH},
        {6,13, DIR_EAST},  {7,14, DIR_NORTH},{8,14, DIR_EAST},
        {4,14, DIR_EAST},  {3,13, DIR_NORTH},{2,14, DIR_EAST},
        {10,14, DIR_EAST}, {11,14, DIR_NORTH},{12,14, DIR_EAST},
        {14,14, DIR_NORTH},{15,13, DIR_NORTH},
    };

    const int num_walls = sizeof(walls) / sizeof(walls[0]);
    for (int i = 0; i < num_walls; i++) {
        maze_set_wall(m, walls[i].x, walls[i].y, walls[i].d);
    }
}

/* ═══════════════════════════════════════════════════════════════════════════
 *  Pretty Printing
 * ═══════════════════════════════════════════════════════════════════════════ */

static const char* dir_name(Direction d) {
    const char *names[] = {"NORTH", "EAST ", "SOUTH", "WEST "};
    return names[d];
}

static const char* cmd_name(CommandType t) {
    switch (t) {
        case CMD_STRAIGHT:       return "STRAIGHT      ";
        case CMD_TURN_LEFT_90:   return "TURN LEFT  90 ";
        case CMD_TURN_RIGHT_90:  return "TURN RIGHT 90 ";
        case CMD_TURN_180:       return "TURN 180      ";
        case CMD_DIAGONAL:       return "DIAGONAL      ";
        case CMD_SMOOTH_LEFT_90: return "SMOOTH LEFT 90";
        case CMD_SMOOTH_RIGHT_90:return "SMOOTH RGHT 90";
        case CMD_SMOOTH_LEFT_180:return "SMOOTH LEFT180";
        case CMD_SMOOTH_RIGHT_180:return"SMOOTH RGT 180";
        case CMD_SS_LEFT_90:     return "SS LEFT 90    ";
        case CMD_SS_RIGHT_90:    return "SS RIGHT 90   ";
        default:                 return "UNKNOWN       ";
    }
}

static void print_maze_with_flood(const MazeMap *m)
{
    printf("\n");
    printf("  ┌");
    for (int x = 0; x < MAZE_SIZE; x++) printf("────┬");
    printf("\b┐\n");

    for (int y = MAZE_SIZE - 1; y >= 0; y--) {
        /* Cell values row */
        printf("%2d│", y);
        for (int x = 0; x < MAZE_SIZE; x++) {
            uint16_t f = m->cells[x][y].flood_value;
            bool is_goal = false;
            for (int g = 0; g < NUM_GOAL_CELLS; g++) {
                if (GOAL_CELLS[g][0] == x && GOAL_CELLS[g][1] == y) is_goal = true;
            }
            if (is_goal) {
                if (f < FLOOD_INFINITY) printf(" *%2d", f);
                else printf("  * ");
            } else if (x == START_X && y == START_Y) {
                if (f < FLOOD_INFINITY) printf(" S%2d", f);
                else printf("  S ");
            } else if (f < FLOOD_INFINITY) {
                printf(" %3d", f);
            } else {
                printf("  · ");
            }

            if (x < MAZE_SIZE - 1) {
                if (maze_has_wall(m, x, y, DIR_EAST)) printf("│");
                else printf(" ");
            }
        }
        printf("│\n");

        /* Horizontal walls row */
        if (y > 0) {
            printf("  ├");
            for (int x = 0; x < MAZE_SIZE; x++) {
                if (maze_has_wall(m, x, y, DIR_SOUTH)) printf("────");
                else printf("    ");
                if (x < MAZE_SIZE - 1) printf("┼");
            }
            printf("┤\n");
        }
    }

    printf("  └");
    for (int x = 0; x < MAZE_SIZE; x++) printf("────┴");
    printf("\b┘\n");
    printf("    ");
    for (int x = 0; x < MAZE_SIZE; x++) printf(" %2d  ", x);
    printf("\n");
}
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

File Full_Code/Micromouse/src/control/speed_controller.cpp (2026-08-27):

/**
 * @file speed_controller.cpp
 * @brief Speed controller implementation with per-motor feedforward.
 * @see speed_controller.h
 *
 * Each wheel has its own PID + feedforward. The feedforward constants
 * (KV_LEFT, KV_RIGHT) can differ to compensate for motor asymmetry
 * (one motor being physically weaker than the other).
 *
 * Feedforward gives ~90% of the required PWM instantly.
 * PID corrects the remaining ~10% for battery voltage changes, friction, etc.
 */

#include "speed_controller.h"
#include "../config/robot_config.h"
#include "../hardware/motor.h"
#include "pid.h"

// ═══════════════════════════════════════════════════════════════════════════
//  PID Gains (conservative — let feedforward do most of the work)
// ═══════════════════════════════════════════════════════════════════════════
// With 1kHz control loop and ~0.58 encoder counts/ms, high PID gains
// amplify quantization noise. Keep KP very low and KD at zero.
#define SPEED_KP 0.05f
#define SPEED_KI 0.02f
#define SPEED_KD 0.0f

// ═══════════════════════════════════════════════════════════════════════════
//  Per-Motor Feedforward Constants
// ═══════════════════════════════════════════════════════════════════════════
// KV = PWM / speed_mm_s. Calibrate separately for each motor.
// If one motor is weaker, it needs a higher KV to produce the same speed.
// To calibrate: run motors at known PWM values (500, 1000, 1500, 2000),
// measure actual speed via Serial, compute KV = PWM / speed, average.
#define FEEDFORWARD_KV_LEFT  3.5f
#define FEEDFORWARD_KV_RIGHT 3.5f

static PID _left_pid(SPEED_KP, SPEED_KI, SPEED_KD, -PWM_MAX, PWM_MAX);
static PID _right_pid(SPEED_KP, SPEED_KI, SPEED_KD, -PWM_MAX, PWM_MAX);

// Track last PWM outputs for debugging (displayed on OLED and Serial)
static int16_t _last_left_pwm = 0;
static int16_t _last_right_pwm = 0;

void speed_controller_init(void) {
  _left_pid.reset();
  _right_pid.reset();
  _last_left_pwm = 0;
  _last_right_pwm = 0;
}

void speed_controller_update(float target_left_speed_mm_s,
                             float target_right_speed_mm_s,
                             float current_left_speed_mm_s,
                             float current_right_speed_mm_s, float dt) {

  // 1. Compute PID corrections
  float left_pid_out =
      _left_pid.compute(target_left_speed_mm_s, current_left_speed_mm_s, dt);
  float right_pid_out =
      _right_pid.compute(target_right_speed_mm_s, current_right_speed_mm_s, dt);

  // 2. Apply per-motor feedforward
  // Feedforward gives the motor approximately the right PWM without waiting
  // for PID to ramp up. Like setting the gas pedal to roughly the right position.
  float left_ff = target_left_speed_mm_s * FEEDFORWARD_KV_LEFT;
  float right_ff = target_right_speed_mm_s * FEEDFORWARD_KV_RIGHT;

  // 3. Combine feedforward + PID and clamp
  float left_total = left_ff + left_pid_out;
  float right_total = right_ff + right_pid_out;

  if (left_total > PWM_MAX)
    left_total = PWM_MAX;
  if (left_total < -PWM_MAX)
    left_total = -PWM_MAX;
  if (right_total > PWM_MAX)
    right_total = PWM_MAX;
  if (right_total < -PWM_MAX)
    right_total = -PWM_MAX;

  // 4. Store for debugging and set motors
  _last_left_pwm = (int16_t)left_total;
  _last_right_pwm = (int16_t)right_total;
  motor_set_both(_last_left_pwm, _last_right_pwm);
}

void speed_controller_reset(void) {
  _left_pid.reset();
  _right_pid.reset();
  _last_left_pwm = 0;
  _last_right_pwm = 0;
}

void speed_controller_set_gains(float kp, float ki, float kd) {
  _left_pid.set_gains(kp, ki, kd);
  _right_pid.set_gains(kp, ki, kd);
}

int16_t speed_controller_get_left_pwm(void) {
  return _last_left_pwm;
}

int16_t speed_controller_get_right_pwm(void) {
  return _last_right_pwm;
}

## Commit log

2026-07-06 Add the photo of the pin diagram of STM32
2026-07-06 Create testing motor codes
2026-07-07 Create motor encoder testing codes
2026-08-27 calibrated cordinate
